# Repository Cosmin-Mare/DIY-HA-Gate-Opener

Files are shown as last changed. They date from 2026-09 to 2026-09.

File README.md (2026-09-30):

# DIY Home Assistant Gate Opener

A battery-powered ESP8266 and a continuous-rotation servo, in a case designed in [Plasticity](https://www.plasticity.xyz/). A button in Home Assistant runs a short forward move and a short return move. That bump is what opens the gate.

The servo has no position sensor, so the move is dead reckoning: degrees divided by a measured degrees-per-second. Forward and backward are tuned separately, and every one of those numbers is editable live in Home Assistant.

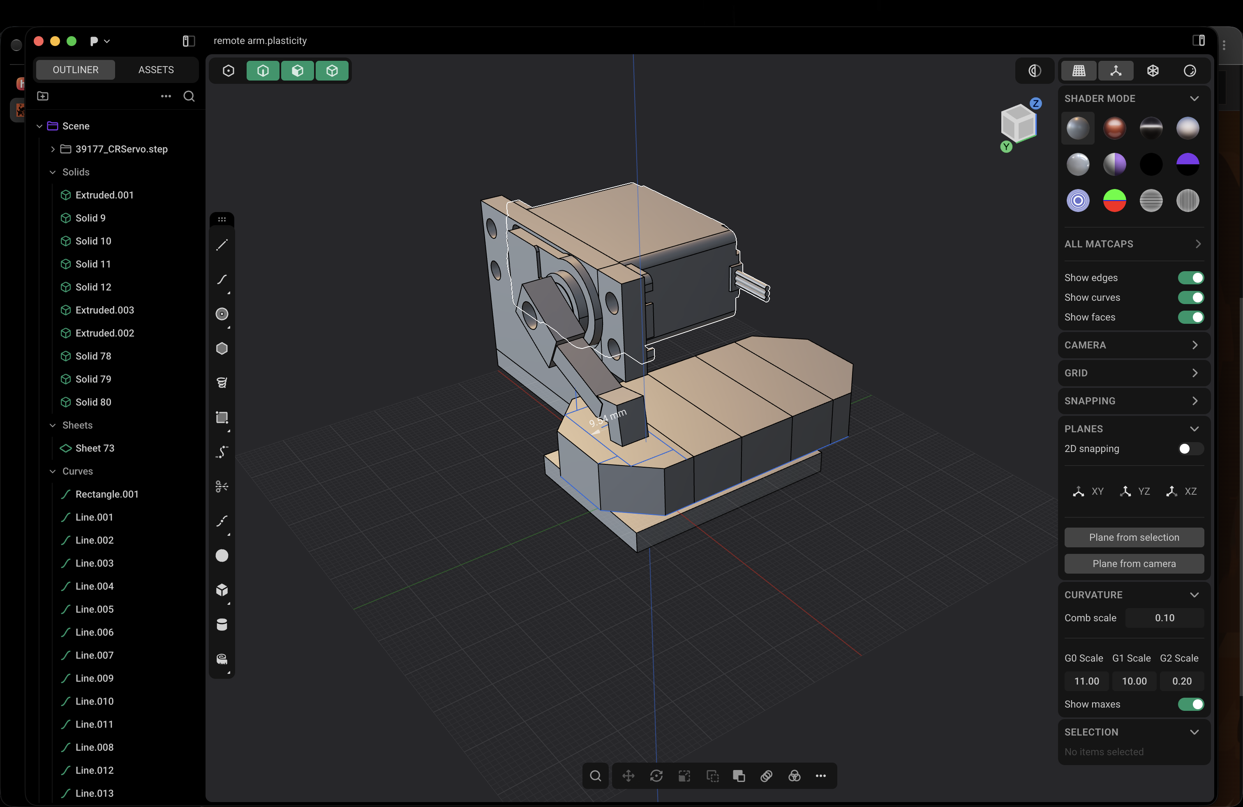
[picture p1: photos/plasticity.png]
Case modeled in Plasticity around the TETRIX 39177, with the printed hand on the axle


## What went into this one

The case was modeled in Plasticity around the TETRIX 39177 servo. The case was printed once. The little hand that sits on the servo axle took three prints, and it is held on with superglue.

Power is an 18650 soldered to a 1S charger board, then to a boost converter set to 6 V. Two wires leave that 6 V output: one to the ESP VIN pin, one to the servo power pin. Grounds are tied together, and the servo signal wire goes to D7.

The firmware is ESPHome. Home Assistant runs on a home server and is published with a Cloudflare Tunnel, so the same Bump button is available on a subdomain away from the house. After it all worked, the wiring was taped down so it would pack into the case.

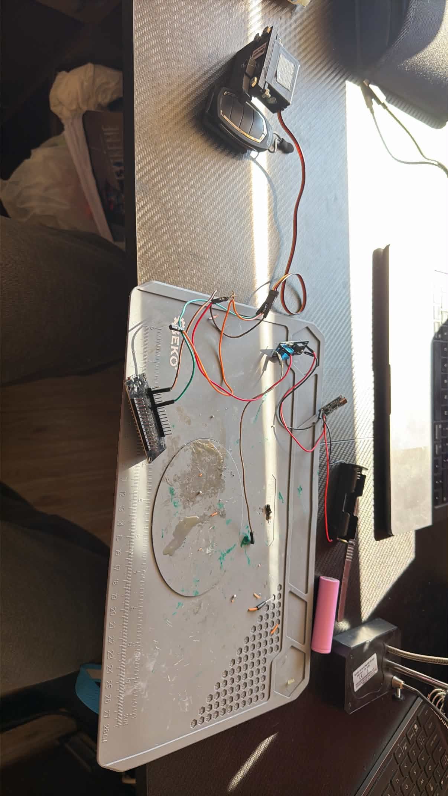
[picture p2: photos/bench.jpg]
Boards, battery, and servo on the bench before they went into the case


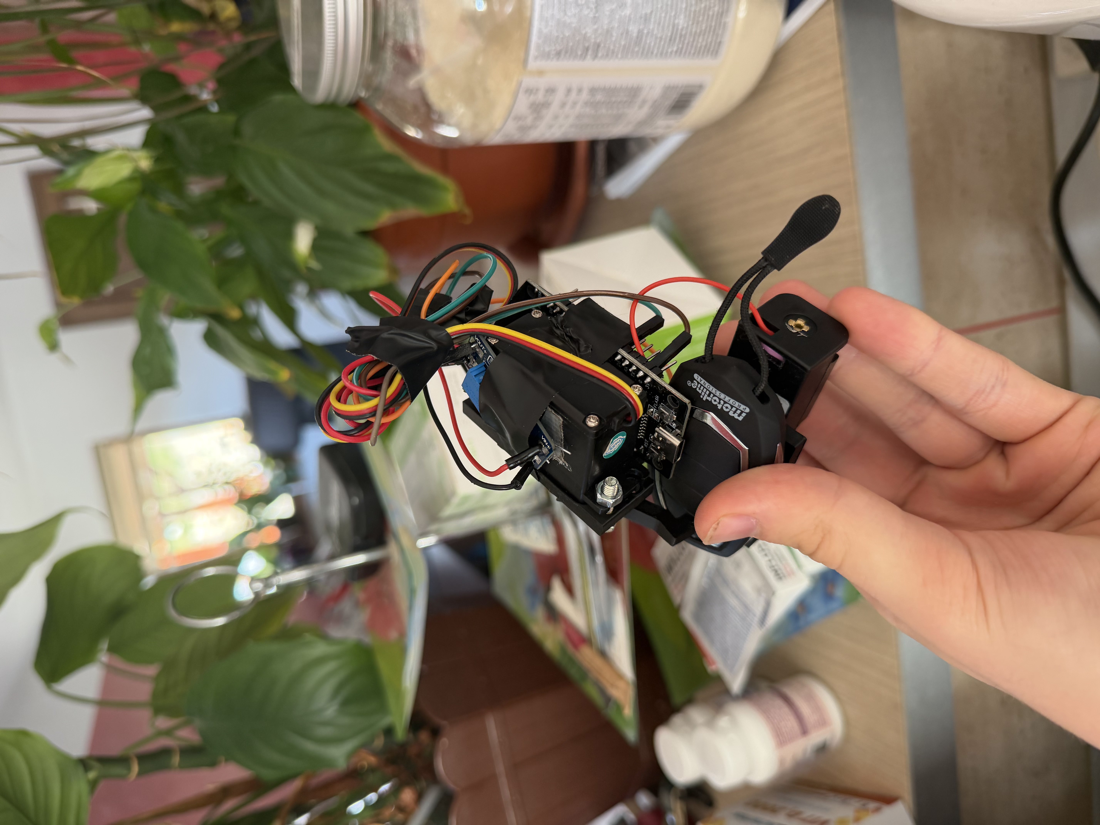
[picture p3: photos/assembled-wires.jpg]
Assembled, with the wiring taped into the printed case


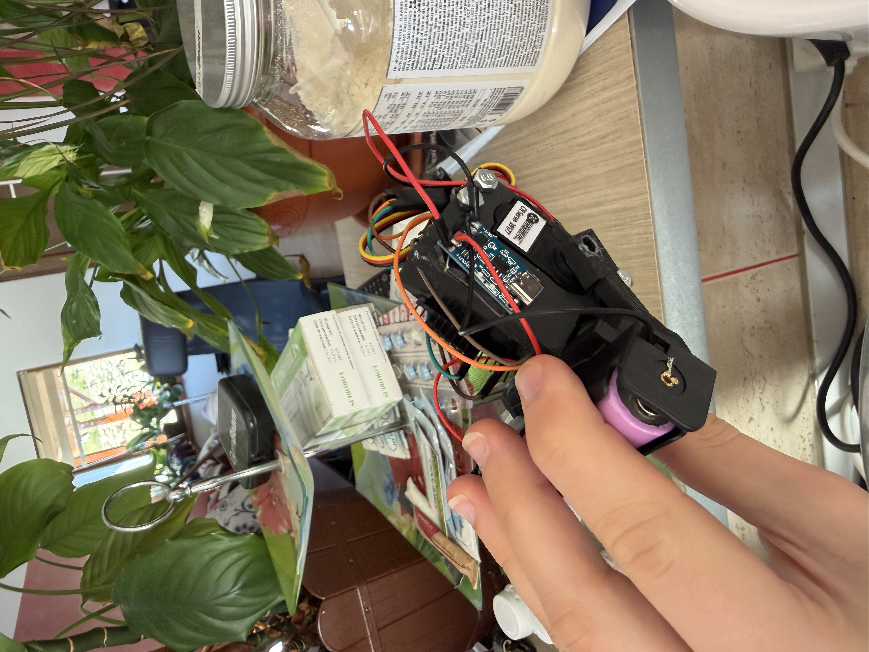
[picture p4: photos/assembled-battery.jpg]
Battery side of the finished unit


## Bill of materials

Links, prices, and what each part does are in [BOM.csv](BOM.csv). Prices were checked on 30 Sep 2026 and do not include shipping.

One of each part is about **$58**. The ESP board is sold as a pair and the charger as a 10-pack, so buying the listings as they are sold is about **$72**.

## Wiring

Set the boost converter to 6 V with a multimeter **before** you connect the ESP or the servo. The trim pot can swing well past that.

```
18650  -->  1S charger  -->  boost converter (set to 6 V)
                                 |
                                 +--> ESP8266 VIN
                                 +--> servo power
                                 +--> common ground (ESP GND and servo ground)
ESP GPIO13 (D7)  -->  servo signal
```

D7 on the HW-625B silkscreen is GPIO13. The PWM rate is 50 Hz, the normal hobby-servo rate.

## Print the case

[`cad/remote-arm.stp`](cad/remote-arm.stp) is the Plasticity assembly. It includes the imported TETRIX servo (`39177_CRServo.step` in the screenshot) so the case and the hand sit correctly on the real part.

Print the case and the hand. The servo body in the file is the bought part, included for fit.

On this build the case fit on the first print. The hand took three tries before it would stay on the axle, and the one that fit is glued on.

## Flash the ESP8266

The config is [`esphome/crservo-controller.yaml`](esphome/crservo-controller.yaml). Put your Wi-Fi name and password in the `wifi:` block at the top before flashing.

### ESPHome dashboard

1. In Home Assistant, install the ESPHome Device Builder add-on and open it.
2. Create a device, open its YAML, and replace the contents with this file.
3. Plug the HW-625B in over USB and choose **Install**.

### Command line

```bash
pip install esphome
esphome run esphome/crservo-controller.yaml
```

The first flash needs the USB cable. Later updates can go over Wi-Fi. OTA is enabled with no password, which is fine on a network you control. There is no fallback hotspot: if the board cannot join Wi-Fi, flash it again over USB.

## Add it to Home Assistant

The device uses the ESPHome native API. Once it is on the same LAN as Home Assistant it shows up under **Settings → Devices & services**. Adopt it there.

These entities appear:

| Entity | What it does |
| --- | --- |
| **Bump** | The gate button. Spins forward, pauses 300 ms, spins back. |
| **CR Servo Stop** | Sets speed to 0. |
| **CR Servo Speed** | Manual slider, −100 (full reverse) to 100 (full forward). Comes back at 0 after a reboot or power loss. |
| **Bump Degrees Forward / Backward** | How far each half of the bump tries to go. |
| **Bump Speed Forward / Backward** | How hard each half spins, in percent. |
| **Bump DPS Forward / Backward** | Measured degrees per second at that speed. Used only for the timing math. |

Search for **Bump** when you add a dashboard card. The entity id is derived from the device name (`crservo-controller`), so picking it from the UI is more reliable than typing an id.

The numbers shipped in the YAML are the ones this build was tuned to:

| | Forward | Backward |
| --- | --- | --- |
| Degrees | 15 | 5 |
| Speed (%) | 18 | 18 |
| Degrees per second | 30 | 30 |

Degree, speed, and DPS values are restored after a reboot. The speed slider is not, so a power loss leaves the servo stopped.

## Tune the bump

The hand position is `time = degrees / degrees_per_second`. The TETRIX servo barely moves below about 5–8% speed, then speeds up steeply, and forward and backward do not match. That is why each direction has its own three numbers.

Changing a speed without remeasuring DPS makes the bump the wrong length. After you change **Bump Speed Forward** or **Bump Speed Backward**:

1. Set **CR Servo Speed** to that same percent. Positive is forward, negative is backward.
2. Let it run for one second, then press **CR Servo Stop**.
3. See how many degrees the hand actually moved.
4. Type that number into the matching **Bump DPS** box.

Those boxes take effect on the next press of **Bump**. No reflash.

If speed 0 still creeps, nudge `idle_level` in the YAML (it is 7.5%, about 1500 µs). If the two directions are lopsided at full speed, nudge `min_level` (3%) and `max_level` (12%). Leave `transition_length: 0s`. ESPHome otherwise ramps the pulse over a full second, and the short bump never reaches the speed you asked for.

## Reach the button from outside the house

Home Assistant on this project runs on a home server. A Cloudflare Tunnel publishes it on a subdomain of a domain you control. The phone loads that hostname, and the Bump button is the same entity as on the LAN.

The ESP8266 does not go through the tunnel. It only has to reach Home Assistant on the local network.

A minimal `cloudflared` ingress, with the hostname swapped for yours:

```yaml
tunnel: <tunnel-id>
credentials-file: /path/to/credentials.json

ingress:
  - hostname: ha.example.com
    service: http://localhost:8123
  - service: http_status:404
```

Point the hostname at Home Assistant's port (8123 on a default install). The ESPHome device still uses the local API.

## Demo

https://github.com/user-attachments/assets/e9069aea-7d2c-4d7b-ab31-095cc686b19b

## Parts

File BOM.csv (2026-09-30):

qty | part | role | supplier | url | listing_price_usd | pack_qty | price_for_one_build_usd | notes
1 | TETRIX MAX continuous-rotation servo (39177 / HSR-1425CR) | Spins the printed hand. 4.8–6 V. Signal on D7. | Pitsco | https://www.pitsco.com/products/tetrix-continuous-rotation-servo | 20.75 | 1 | 20.75 | Clearance price, checked 30 Sep 2026, USD, shipping and tax excluded. Also listed by part number at Techno-Tek for 22.00: https://techno-tek.com/product/tetrix-max-continuous-rotation-servo-39177-hsr-1425cr/
1 | HW-625B, or a NodeMCU ESP-12 with CH340 (D7 = GPIO13) | ESPHome controller. USB for the first flash. | MakerFocus | https://www.makerfocus.com/products/2pcs-esp8266-nodemcu-lua-ch340-esp-12e-internet-wifi-development-board-for-arduino | 13.99 | 2 | 7.00 | This build used an HW-625B, a NodeMCU-style ESP-12 board. D7 on the silkscreen is GPIO13. The link is a 2-pack of that same class of board.
1 | MT3608 boost module | Steps the cell up. Set the trim pot to 6 V before connecting anything else. | ICStation | https://www.icstation.com/mobile/icstation-step-converter-module-boost-converter-power-supply-module-icsa004a-p-3448.html | 0.90 | 1 | 0.90
1 | TP4056 1S charger with protection | Charges the 18650 from 5 V USB. | HiLetgo on Amazon | https://www.amazon.com/HiLetgo-Lithium-Battery-Charging-Protect/dp/B00LTQU2RK | 7.79 | 10 | 0.78
1 | Samsung INR18650-30Q | Single lithium-ion cell. 3000 mAh, 15 A, enough for this servo. | IMR Batteries | https://imrbatteries.com/products/samsung-30q-18650-3000mah-15a-battery | 5.99 | 1 | 5.99 | Flat-top unprotected cell. The TP4056 module's protection circuit is the protection on this build. The cell in the photos sits in a single 18650 holder with leads; any leaded one-cell holder fits.
1 | Polymaker Panchroma PLA, black, 1.75 mm, 1 kg | Case (one print) and servo hand (three prints). | Polymaker | https://www.amazon.com/Panchroma-Filament-Printing-Compatible-Miniatures/dp/B0FC1RT6M8 | 14.49 | 1 | 14.49 | A spool is far more than this project uses.
1 | Gorilla Super Glue Gel, 15 g | Holds the hand on the servo axle. | Amazon | https://www.amazon.com/dp/B01GWD35YQ | 8.02 | 1 | 8.02

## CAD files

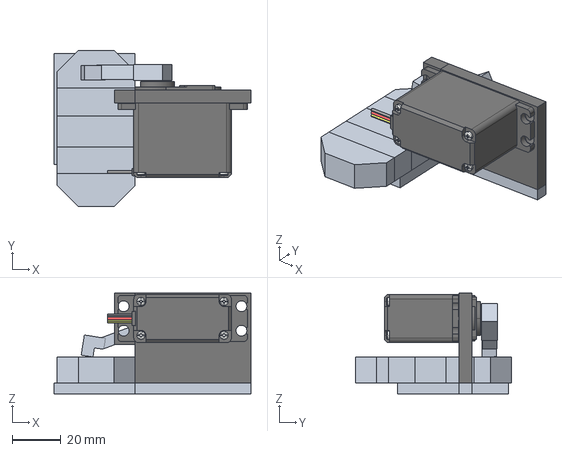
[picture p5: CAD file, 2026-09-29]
cad/remote-arm.stp
80.7 x 64.0 x 41.3 mm

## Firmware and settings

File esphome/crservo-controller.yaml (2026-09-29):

# ESPHome config for HW-625B (ESP-12F / ESP8266) driving a
# TETRIX CRServo 39177 (continuous-rotation servo) on D7 / GPIO13.
#
# NOTE: The CRServo has no position feedback — it's speed/direction only,
# like a PWM-controlled motor. This exposes a -100..100 "speed" slider to
# Home Assistant: negative = reverse, 0 = stop, positive = forward.
#
# It also adds a "Bump" button that spins forward for a calculated time,
# then spins back for a calculated time, to move roughly N degrees and
# return. Since there's no position sensor, this is pure dead-reckoning
# (speed x time), and this servo's speed response is very non-linear (see
# the deadband note on the Bump DPS entities below) -- so degrees, speed,
# AND the deg/sec calibration for each direction are ALL exposed as their
# own number entities in Home Assistant. That way you can retune any of
# it live without reflashing.
#
# Put this file in your ESPHome dashboard (or `esphome/` folder on your
# server) and fill in your wifi credentials below before flashing.

esphome:
  name: crservo-controller
  friendly_name: CR Servo Controller

esp8266:
  board: esp12e   # matches ESP-12F modules (HW-625B, same as your IR blaster)

# Logging over serial/OTA
logger:

# Home Assistant native API (no encryption key = unencrypted, fine on a home LAN)
api:

ota:
  - platform: esphome
    # no password = anyone on your network could push new firmware to this
    # device; fine on a home network you control, add a password later if needed

wifi:
  ssid: "YOUR_WIFI_SSID"
  password: "YOUR_WIFI_PASSWORD"

  # No fallback hotspot configured — if it can't reach your wifi, you'll need
  # a USB cable to reflash it rather than connecting to a temporary AP.
  # (Add an `ap:` block back later if you want that safety net.)

# --- Servo signal output ---
output:
  - platform: esp8266_pwm
    id: crservo_pwm
    pin: GPIO13          # D7 on the HW-625B silkscreen
    frequency: 50 Hz      # standard hobby-servo PWM rate

servo:
  - id: crservo
    output: crservo_pwm
    # IMPORTANT: ESPHome's servo component smooths speed changes over
    # transition_length (default 1s!) instead of applying them instantly.
    # That's fine for the manual 1s-long calibration tests, but it wrecks
    # the short "bump" pulses -- the servo never reaches full commanded
    # speed before the next write() cuts in, unevenly between the forward
    # and reverse legs. Setting this to 0 makes write() apply immediately.
    transition_length: 0s
    # Standard 500-2400us pulse range expressed as % of the 20ms period.
    # Tetrix CRServo generally follows standard servo timing, but if full
    # speed feels weak/asymmetric or it doesn't fully stop at "0", nudge
    # these slightly (e.g. idle_level 7.4% / 7.6%) until it sits still
    # at 0 and spins evenly in both directions.
    min_level: 3%          # ~600us  -> full reverse
    idle_level: 7.5%        # ~1500us -> stop
    max_level: 12%          # ~2400us -> full forward
    # No auto_detach: keep the PWM signal held so the servo holds "stop"
    # firmly instead of free-spinning when the signal is released.

# --- Home Assistant control: -100 (full reverse) .. 0 (stop) .. 100 (full forward) ---
number:
  - platform: template
    name: "CR Servo Speed"
    id: crservo_speed
    icon: mdi:rotate-3d-variant
    min_value: -100
    max_value: 100
    step: 1
    initial_value: 0
    restore_value: false   # starts at stop after reboot/power loss, for safety
    optimistic: true
    on_value:
      then:
        - lambda: |-
            id(crservo).write(x / 100.0);

  # --- Bump tuning, all live-editable from Home Assistant, all restored ---
  # --- across reboots. "mode: box" gives a numeric entry field instead   ---
  # --- of a slider, so you can type exact values like 1.5.              ---

  # How far the "Bump" button moves it, in degrees (estimated), each way
  - platform: template
    name: "Bump Degrees Forward"
    id: bump_deg_fwd
    icon: mdi:angle-acute
    mode: box
    min_value: 0
    max_value: 180
    step: 0.1
    initial_value: 15
    restore_value: true
    optimistic: true

  - platform: template
    name: "Bump Degrees Backward"
    id: bump_deg_rev
    icon: mdi:angle-acute
    mode: box
    min_value: 0
    max_value: 180
    step: 0.1
    initial_value: 5
    restore_value: true
    optimistic: true

  # Speed (% of full, always positive here -- direction is fixed by which
  # leg it drives) used for each leg of the bump move
  - platform: template
    name: "Bump Speed Forward"
    id: bump_speed_fwd
    icon: mdi:speedometer
    mode: box
    min_value: 1
    max_value: 100
    step: 0.5
    initial_value: 18
    restore_value: true
    optimistic: true

  - platform: template
    name: "Bump Speed Backward"
    id: bump_speed_rev
    icon: mdi:speedometer
    mode: box
    min_value: 1
    max_value: 100
    step: 0.5
    initial_value: 18
    restore_value: true
    optimistic: true
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

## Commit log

2026-09-29 Add the gate opener firmware, case, and setup guide.
    [crservo-controller.yaml, remote-arm.stp]
2026-09-30 Add a bill of materials with current prices.
2026-09-30 Replace the bill of materials markdown with a CSV.
    [BOM.csv]
